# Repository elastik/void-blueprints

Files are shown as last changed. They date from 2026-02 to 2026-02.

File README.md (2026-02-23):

# Void Blueprints

Open-source mushroom cultivation dome — CAD designs, firmware, and build documentation.

The Void is a UV-lit mushroom cultivation chamber that doubles as a living art piece. Print it on any consumer 3D printer, assemble it with readily available components, and grow gourmet mushrooms at home.

## What's Inside

| Directory | Contents | License |
|---|---|---|
| `cad/` | OpenSCAD source files and exported STLs | [CERN-OHL-P-2.0](LICENSE-HARDWARE) |
| `firmware/` | ESP32 PlatformIO project (Void Core) | [MIT](LICENSE-FIRMWARE) |
| `*.md` | Build guides, BOM, assembly instructions | [CC BY 4.0](LICENSE-DOCS) |

## Quick Start

1. **Download STLs** from the [latest release](https://github.com/elastik/void-blueprints/releases/latest)
2. **Print** using settings in [PRINT-SETTINGS.md](PRINT-SETTINGS.md)
3. **Source parts** from [BOM.md](BOM.md) (~$35-85 depending on variant)
4. **Assemble** following [ASSEMBLY-GUIDE.md](ASSEMBLY-GUIDE.md)
5. **Flash firmware** per [FIRMWARE-DOCS.md](FIRMWARE-DOCS.md) (Void Core variant only)

## Variants

| Variant | Description | Electronics | Price Range |
|---|---|---|---|
| **The Void** | Base dome, passive humidity | None | ~$35 |
| **Void Core** | Smart dome with sensors, fans, UV-C | ESP32 + sensors | ~$85 |
| **Dark Dome** | Simplified Void Core, no UV-C | ESP32 + sensors | ~$65 |

## Documentation

- [BUILD-GUIDE.md](BUILD-GUIDE.md) — Complete build walkthrough
- [PARTS-GUIDE.md](PARTS-GUIDE.md) — Component sourcing with suppliers
- [BOM.md](BOM.md) — Bill of materials with prices
- [ASSEMBLY-GUIDE.md](ASSEMBLY-GUIDE.md) — Step-by-step assembly
- [PRINT-SETTINGS.md](PRINT-SETTINGS.md) — 3D printing parameters
- [FIRMWARE-DOCS.md](FIRMWARE-DOCS.md) — Electronics and firmware
- [PRODUCT-SPEC.md](PRODUCT-SPEC.md) — Full engineering specification
- [SPECIES-REQUIREMENTS.md](SPECIES-REQUIREMENTS.md) — Mushroom growing conditions
- [CONTRIBUTING.md](CONTRIBUTING.md) — How to contribute

## Contributing

See [CONTRIBUTING.md](CONTRIBUTING.md) for guidelines. All skill levels welcome — from fixing typos to designing PCBs.

## Community

- Website: [thevoidgrows.com](https://thevoidgrows.com)
- Companion App: [github.com/elastik/thevoidgrows-app](https://github.com/elastik/thevoidgrows-app)
- Social: #VoidGrows #VoidBlueprints

## License

- **Hardware** (CAD, STLs): [CERN-OHL-P-2.0](LICENSE-HARDWARE)
- **Firmware**: [MIT](LICENSE-FIRMWARE)
- **Documentation**: [CC BY 4.0](LICENSE-DOCS)

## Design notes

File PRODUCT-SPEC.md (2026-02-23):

# The Void -- Product Design Specification

> Technical specification for The Void cultivation dome and its variants.
> All design targets derived from SPECIES-REQUIREMENTS.md universal design envelope.
> This document is the engineering reference for prototyping, 3D printing, and injection molding.

---

## 1. Design Overview

### Product Identity

**The Void** is a UV-lit mushroom cultivation dome -- a sealed growing chamber that doubles as a living art piece. It houses a pre-inoculated substrate block (Void Pack) inside a smoked dome on a matte black base, illuminated by UV-A and blue LEDs. USB-C powered. No moving parts in the base model.

### Design Philosophy

1. **Functional cultivation chamber first.** Every aesthetic choice must serve or not compromise growing conditions.
2. **Living art piece.** The dome sits on a desk, shelf, or nightstand. It must look intentional, not like lab equipment.
3. **UV aesthetic defines the brand.** The purple glow under UV-A light IS the product experience.
4. **Simplicity scales down, intelligence scales up.** The base Void is dead simple (LEDs + vents). Complexity lives in Void Core.

### Variant Matrix

| Variant | Description | MSRP | Key Differences |
|---|---|---|---|
| **The Void** | Base cultivation dome. Smoked dome, matte black base, UV-A + blue LEDs, passive airflow, UV-C sterilization, USB-C power. Physical button for mode cycling. | $79 | No microcontroller (or ATtiny). No sensors. No fan. No humidifier. No camera. |
| **Void Core** | Smart dome upgrade. Adds Pi Zero W 2, BME280 sensor, piezo humidifier, PWM fan, camera module, Wi-Fi, app control. | $299 | Active humidity control. Active airflow. Programmable light modes. Timelapse camera. App integration. |
| **Dark Dome** | No-LED variant for bioluminescent species (Panellus stipticus). Same physical shell, no lighting electronics. | $49 | No LEDs. No UV-A, no blue, no UV-C. Passive airflow only. Opaque or clear dome option. |

### Overall Dimensions

**Validated dimensions: 8.0" (203mm) diameter x 10.0" (254mm) total height.**

Validation against species requirements:

| Constraint | Requirement | 8" x 10" Fit | Notes |
|---|---|---|---|
| Substrate block width | Custom 1-2 lb block, ~4.5-5" diameter | 1.5-1.75" clearance on each side | Adequate for lateral fruiting (oysters) |
| Lion's Mane fruiting body | Up to 4-8" diameter | Single fruit body fits; very large specimens may contact dome wall | Acceptable -- large fruit bodies are the success case |
| Oyster cluster spread | 4-6" lateral spread | Fits with clearance; multiple clusters may crowd | Position block so clusters grow upward |
| Reishi antler height | Antlers grow upward, typically 4-8" tall | ~5-6" vertical clearance above substrate surface | Adequate for typical antler growth |
| Shiitake cap diameter | 2-4" individual caps | Fits easily | No concerns |
| Panellus stipticus | Small fruiting bodies, caps up to 3cm | Fits easily | No concerns |
| Airflow volume | ~400 cubic inches chamber volume for passive FAE calculations | Sufficient for convective flow if vents are properly sized | See Section 4 |

**Dimension breakdown:**

| Component | Dimension | Notes |
|---|---|---|
| Total height | 10.0" (254mm) | Dome + base assembled |
| Total diameter | 8.0" (203mm) | Widest point at dome-base junction |
| Dome height | 6.5" (165mm) | From base top to dome apex |
| Base height | 3.5" (89mm) | Houses electronics, substrate platform, and airflow plenum |
| Dome inner diameter | 7.5" (190mm) | Wall thickness reduces usable interior |
| Substrate platform diameter | 5.5" (140mm) | Centered in base; sized for 1-2 lb Void Pack |
| Vertical clearance above substrate | ~5.5-6.0" (140-152mm) | From top of substrate block to dome interior apex |

### Chamber Volume

- Dome interior volume (hemisphere approximation): ~110 cubic inches (~1.8 liters)
- Effective growing chamber (above substrate): ~90-100 cubic inches (~1.5-1.6 liters)
- This small volume is both a feature (humidity retention) and a challenge (CO2 accumulation)

---

## 2. Dome Shell

### Geometry

**Truncated hemisphere with vertical sidewall transition.** The dome is not a pure hemisphere -- it features a short vertical sidewall (approximately 1.0" / 25mm) at the base that transitions into a hemispherical curve. This geometry provides:

1. Maximum interior volume at the widest point where mushroom clusters grow laterally
2. Clean visual silhouette -- more "dome" than "ball"
3. A defined seating lip for the dome-to-base interface
4. Better airflow -- vertical walls at the base allow vents to channel air upward along the dome interior

### Material Options

| Material | Method | Pros | Cons | Recommended For |
|---|---|---|---|---|
| **Smoked polycarbonate** | Injection molding | Excellent impact resistance, natural UV blocking, high clarity with smoke tint, premium feel | Higher mold cost | Production Void (Kickstarter fulfillment) |
| **Smoked PETG** | 3D printing (FDM/SLA) | Printable, good humidity resistance, tintable, adequate clarity | Layer lines (FDM), less impact-resistant than PC | Void Blueprints (community prints), prototyping |
| **Smoked acrylic (PMMA)** | Laser cut + thermoform, or injection mold | Excellent optical clarity, good UV blocking, lightweight | Brittle, scratches easily | Budget production option |

**Primary specification: Smoked polycarbonate for production units.**

### Wall Thickness

| Parameter | Value | Rationale |
|---|---|---|
| Dome wall thickness | 2.0mm (0.079") | Structural integrity + light diffusion. Thin enough for UV-A glow transmission, thick enough to resist accidental drops. |
| Smoke tint level | 50-60% visible light transmission (VLT) | Dark enough to create dramatic UV glow contrast, light enough to see mushrooms growing inside under ambient room light. |
| UV-C opacity | 100% blocked below 300nm | Polycarbonate naturally blocks UV-C. This is the primary safety barrier -- the dome IS the UV-C enclosure. |
| UV-A transmission | 30-50% at 395nm | Allows UV-A glow to be visible from outside the dome. Polycarbonate transmits adequately at 395nm. |

### Finish

- **Exterior:** Smooth, high-gloss smoked tint. The dome should look like smoked glass.
- **Interior:** Smooth. No texture that could trap moisture or contaminants.
- **Anti-fog consideration:** Interior condensation is expected at 85-90% RH. A hydrophilic anti-fog coating (or design that promotes sheeting rather than droplets) prevents obscured viewing. Evaluate anti-fog coatings rated for high-humidity environments during prototyping.

### Dome-to-Base Interface

**Friction-fit with alignment notch.**

- The dome seats into a recessed channel (2mm deep) machined/molded into the base top surface
- A single alignment notch ensures consistent dome orientation (important for vent alignment)
- Friction fit is snug enough to maintain seal but loose enough for easy one-hand removal
- No locking mechanism -- the dome lifts straight off for substrate block swaps
- A silicone gasket ring (1.5mm) in the base channel creates a humidity seal while allowing easy removal

**Magnetic reed switch integration:** A small magnet (6mm x 2mm neodymium disc) is embedded in the dome's seating lip. A corresponding reed switch in the base detects dome presence for the UV-C safety interlock (see Section 7). The dome must be fully seated for UV-C to activate.

---

## 3. Base Unit

### Dimensions

| Parameter | Value | Notes |
|---|---|---|
| Outer diameter | 8.0" (203mm) | Matches dome diameter for flush fit |
| Height | 3.5" (89mm) | Houses substrate platform + electronics + airflow plenum |
| Base footprint | 8.0" diameter circle | Flat bottom for desk stability |
| Weight (empty, base only) | ~350-450g target | Heavy enough for stability, light enough for shipping |

### Material

**Matte black ABS (injection molded) or PETG (3D printed).**

- ABS for production: excellent finish, paintable, dimensionally stable
- PETG for Void Blueprints: printable, humidity-resistant, adequate strength
- Finish: matte black, soft-touch texture on exterior surfaces
- Interior surfaces: smooth for easy cleaning

### Internal Layout (Top to Bottom)

```
    +----- Dome seating channel (top rim) -----+
    |                                           |
    |  [Substrate platform - raised 0.5"]       |
    |  [  5.5" diameter, with drain slots  ]    |
    |                                           |
    |--- LED ring (UV-A + Blue) mounted here ---|
    |                                           |
    |  [Airflow plenum - 1.0" height]           |
    |  [  Intake vents around perimeter    ]    |
    |                                           |
    |--- Electronics shelf ----------------------|
    |  [LED driver / UV-C control / button]     |
    |  [USB-C port at rear]                     |
    |                                           |
    +-- Base bottom (flat, with rubber feet) ----+
```

### Substrate Platform

| Parameter | Value | Notes |
|---|---|---|
| Platform diameter | 5.5" (140mm) | Centered; sized for custom 1-2 lb Void Pack blocks |
| Platform depth (recessed) | 0.5" (13mm) | Shallow well to center the block and catch drainage |
| Surface | Perforated / slotted | 4-6 drain slots for excess moisture to drain into airflow plenum below |
| Rim height | 0.25" (6mm) raised lip | Prevents block from sliding during dome removal |

### Cable Routing

- USB-C port location: rear-center of base, recessed 3mm into the housing
- Internal cable routing: flat flex cable from USB-C port to electronics shelf
- Cable exit: downward-facing port so cable routes down to desk surface cleanly
- Strain relief: molded into the port recess

### Stability

- Four silicone rubber feet (12mm diameter, 3mm tall) on base bottom
- Total assembled weight target: 600-800g (dome + base, no substrate)
- Center of gravity is low (electronics and base mass are below midpoint)
- Stable on typical desk surfaces; no risk of tipping from dome removal

---

## 4. Airflow System (Fresh Air Exchange)

### Design Challenge

CO2 management is the #1 engineering challenge for the dome. From SPECIES-REQUIREMENTS.md:

- Lion's Mane (flagship): requires < 800 ppm CO2, 5-8 air exchanges/hour
- Blue/Pink Oyster: requires < 800-1000 ppm CO2, 4-6 exchanges/hour
- Chamber volume is only ~1.5-1.6 liters of effective growing space
- A respiring substrate block in this small volume accumulates CO2 rapidly
- The dome must exchange air passively (no fan in base Void) while maintaining 85-90% RH

### Approach: Passive Convective Airflow

The base Void uses **passive convective (chimney effect) airflow** -- warm, CO2-rich, humid air rises and exits through upper dome vents, while cool fresh air enters through lower base intake vents.

**Why passive works:** The substrate block generates metabolic heat (0.5-2 degrees F above ambient), creating a temperature differential that drives natural convection. The dome's vertical profile (10" tall) provides sufficient chimney height for meaningful convective flow.

### Vent Design

#### Intake Vents (Base)

| Parameter | Value | Notes |
|---|---|---|
| Location | Lower perimeter of base unit, evenly spaced | 360-degree intake for omnidirectional fresh air |
| Quantity | 8 slots | Evenly distributed around circumference |
| Individual slot size | 15mm wide x 5mm tall (0.6" x 0.2") | Small enough for contamination barrier, large enough for airflow |
| Total intake area | ~600 mm2 (~0.93 in2) | Sized for target exchange rate (see calculations below) |
| Filter | Micropore tape (3M Micropore or equivalent) | Blocks contaminant spores (>0.3 um) while allowing air passage |
| Adjustable | No (base Void) / Yes (Void Core -- motorized damper) | Base Void has fixed vents; simplicity over tunability |

#### Exhaust Vents (Dome Upper)

| Parameter | Value | Notes |
|---|---|---|
| Location | Upper third of dome, near apex | Warm CO2-rich air naturally rises here |
| Quantity | 4 vent holes | Evenly spaced around dome circumference, ~60 degrees from apex |
| Individual hole diameter | 12mm (0.47") | Sized for exhaust flow rate |
| Total exhaust area | ~452 mm2 (~0.70 in2) | Slightly less than intake -- creates slight positive pressure tendency |
| Filter | Micropore tape (replaceable) | User-accessible for replacement; contaminant barrier |
| Cover design | Recessed ring with snap-in filter disc | Clean exterior appearance; easy filter swap |

#### Airflow Rate Calculation

Target: 4-6 air exchanges per hour (satisfies all species except antler reishi).

- Chamber volume: ~1.6 liters
- At 4 exchanges/hour: 6.4 liters/hour = 107 ml/min = 1.78 ml/sec
- At 6 exchanges/hour: 9.6 liters/hour = 160 ml/min = 2.67 ml/sec

Natural convection through the vent openings at a 1-2 degree F temperature differential and 10" chimney height produces estimated flow rates of 2-5 ml/sec through the specified vent areas. This falls within the target range.

**Uncertainty note:** These are engineering estimates based on simplified chimney effect calculations. Actual airflow depends on ambient conditions (room air currents, temperature, barometric pressure), vent geometry, and micropore tape resistance. Prototype testing with CO2 monitoring is essential to validate vent sizing and may require iteration.

### Airflow Path

```
CROSS-SECTION VIEW (not to scale):

              Exhaust vents (x4)
                 \   |   /
          +-------[V][V]--------+
         /    Dome (smoked PC)    \
        /                          \
       |   ~~~~~~~~~~~~~~~~~~~~~~~~ |   <- Humid air layer
       |                            |
       |    +------------------+    |
       |    | Mushroom fruiting|    |
       |    |    bodies grow   |    |
       |    |     upward       |    |
       |    +------------------+    |
       |    |  Void Pack block |    |
       |    | (substrate 4.5") |    |
       |    +--------+---------+    |
       |             |drain slots   |
       +====[LED RING (UV-A+Blue)]===+  <- Dome/base junction
       |                            |
       |   [Airflow plenum 1.0"]    |
       |                            |
  -->[V]  Intake      Intake   [V]<--   <- Base intake vents (x8)
       |   vents       vents        |      Fresh air enters
       |                            |
       |  [Electronics: LED driver] |
       |  [UV-C ctrl] [Button]      |
       |        [USB-C port]        |
       +----(rubber feet)x4---------+
       ================================   <- Desk surface
```

**Flow path:** Fresh air enters through base intake vents -> passes through airflow plenum beneath substrate platform -> rises through drain slots in platform -> passes over/around substrate block and fruiting bodies -> warm CO2-rich air rises to dome apex -> exits through upper dome exhaust vents.

### Void Core Upgrade: Active Airflow

| Parameter | Value | Notes |
|---|---|---|
| Fan type | 30mm axial fan (5V DC) | Mounted in base airflow plenum |
| Fan speed | PWM controlled, 0-5000 RPM | App-adjustable; auto-mode based on CO2 sensor reading |
| Noise level | < 25 dB at typical operating speed | Near-silent operation |
| Air exchange rate | 4-12 exchanges/hour (adjustable) | Higher rates available for CO2-sensitive species |
| CO2 sensor | SCD30 or SCD40 (Sensirion) via BME280 combo | Triggers fan speed increase when CO2 > 600 ppm |

### Reishi Antler Mode

For reishi antler form cultivation (requires > 2000 ppm CO2), users should cover or tape over 6 of 8 base intake vents and 3 of 4 dome exhaust vents. This reduces air exchange to ~1 exchange/hour, allowing CO2 to accumulate.

- **Base Void:** Manual vent covering with included silicone plugs (4 plugs included with Reishi Void Pack)
- **Void Core:** App-controlled motorized dampers on intake and exhaust vents

---

## 5. Humidity Management

### Design Target

**85-90% RH** inside the dome during active fruiting. This satisfies all target species:

| Species | Required RH | 85-90% Target | Status |
|---|---|---|---|
| Lion's Mane | 85-95% | Within range | OK |
| Blue Oyster | 85-95% | Within range | OK |
| Pink Oyster | 85-95% (min 70%) | Within range | OK |
| Shiitake | 85-95% early, 60-80% late | Within range for early; naturally drops as vents exchange air in late stage | OK |
| Reishi | 80-90% | Within range | OK |
| Panellus stipticus | 85-95% | Within range | OK |

### Base Void: Passive Humidity (No Moving Parts)

The base Void maintains humidity through three mechanisms:

1. **Substrate moisture:** The Void Pack substrate block is hydrated to 60-65% moisture content. As the mycelium respires, it releases moisture vapor into the chamber. A 1-2 lb block contains approximately 300-600 ml of water, providing sustained humidity for the full grow cycle (2-4 weeks for most species).

2. **Sealed dome retention:** The smoked polycarbonate dome with silicone gasket creates a near-sealed environment. Humidity loss occurs only through the sized vents, which are restricted by micropore tape. This natural retention keeps RH high.

3. **Vent sizing balance:** The vents are sized to allow adequate FAE (4-6 exchanges/hour) while losing minimal humidity. Micropore tape on vents acts as a partial humidity barrier -- air passes through but water vapor transport is reduced. The vent areas specified in Section 4 were designed to balance CO2 removal against humidity retention.

**Expected behavior:** In a typical indoor environment (68-75 degrees F, 40-60% ambient RH), the dome interior should stabilize at 80-92% RH with a fresh Void Pack. As the substrate dries over the grow cycle, RH gradually decreases. For multi-flush grows, users soak the substrate block between flushes to rehydrate.

**Condensation management:** At 85-90% RH, condensation will form on the dome interior, especially in the upper dome where warm moist air meets the cooler dome surface. This is normal and expected. The dome geometry (curved interior) encourages condensation droplets to run down the walls and return to the base rather than dripping directly onto fruiting bodies. The anti-fog coating (Section 2) promotes sheeting over beading for better visibility.

### Void Core: Active Humidity Control

| Parameter | Value | Notes |
|---|---|---|
| Humidifier type | Piezoelectric ultrasonic mist disc (20mm, 113 KHz) | Low-power, fine mist, no heat |
| Reservoir | 100 ml integrated reservoir in base | Refill via pour port on base exterior; lasts ~3-5 days at normal operation |
| Mist output | 20-40 ml/hour (adjustable via PWM) | Triggered by BME280 humidity reading |
| Control logic | Maintain setpoint +/- 2% RH | Default 88% RH; user-adjustable via app (80-95% range) |
| Fill indicator | LED color change or app notification when reservoir low | Prevents dry-run damage to piezo disc |

### Humidity Monitoring (Void Core Only)

The BME280 sensor (temperature + humidity + barometric pressure) provides real-time RH data to the Pi Zero W 2. The control loop:

1. Read humidity every 30 seconds
2. If RH < (setpoint - 2%), activate mist disc at duty cycle proportional to deficit
3. If RH > (setpoint + 2%), pause mist disc; optionally increase fan speed briefly to vent excess
4. Log data for timelapse correlation and grow analytics in the Void app

---

## 6. Access & Maintenance

### Dome Removal: Lift-Off Design

The dome **lifts straight up and off** the base. No hinge, no twist-lock, no bayonet mount.

**Rationale:**
- Simplest possible mechanism (no moving parts, no wear points)
- One-hand operation: grip dome at widest point, lift straight up
- Full 360-degree access to the interior -- no hinge blocking one side
- Easy to clean -- dome is completely separable
- Easiest manufacturing (no hinge hardware, no alignment mechanisms)
- Compatible with UV-C safety interlock (magnetic reed switch detects dome presence)

### Substrate Block Replacement Workflow

**Standard grow cycle (base Void):**

1. Receive Void Pack (pre-colonized substrate block in sealed bag)
2. Remove Void Pack from bag
3. Lift dome off base
4. Place Void Pack on substrate platform (centered in recessed well)
5. Place dome back on base (align notch)
6. Press button to select light mode (UV-A glow, blue fruiting light, or both)
7. Wait 7-21 days (species dependent) -- mushrooms fruit
8. Lift dome to harvest mushrooms
9. Replace dome; continue for additional flushes (soak block between flushes)
10. When spent, remove old block
11. (Optional) Press and hold button for UV-C sterilization cycle (15 minutes, dome must be seated)
12. Place new Void Pack; repeat from step 5

**Between-grow cleaning:**

1. Remove spent substrate block; discard or compost
2. Lift dome off base
3. Wipe dome interior with damp cloth (mild soap if needed)
4. Wipe substrate platform and base interior
5. Replace micropore tape on vents if contaminated or clogged (every 2-3 grow cycles)
6. (Optional) Run UV-C sterilization cycle with dome seated and chamber empty
7. Place new Void Pack

### Micropore Tape Replacement

- Intake vent filters: accessed from base exterior; peel old tape, apply new strip
- Exhaust vent filters: accessed from dome exterior; snap-out filter disc, replace tape, snap back in
- Replacement tape included in Void Pack packaging (enough for one grow cycle)
- Also available separately or in bulk from standard suppliers (3M Micropore surgical tape)

### Maintenance Schedule

| Task | Frequency | Difficulty |
|---|---|---|
| Harvest mushrooms | Every 7-21 days during fruiting | Easy -- lift dome, cut/twist fruit bodies |
| Soak substrate block (between flushes) | Every 10-14 days | Easy -- remove block, soak in water 12-24 hours, return |
| Replace Void Pack | Every 1-3 months (species dependent) | Easy -- swap blocks |
| Wipe dome interior | Between grows | Easy -- damp cloth |
| Replace micropore tape on vents | Every 2-3 grows | Easy -- peel and stick |
| UV-C sterilization cycle | Between grows (recommended) | Easy -- press and hold button, wait 15 min |
| Refill humidifier reservoir (Void Core) | Every 3-5 days | Easy -- pour water into fill port |

### Dark Dome Variant Notes

The Dark Dome follows the same physical design as The Void with these differences:

- **No LED ring:** The base has no UV-A, blue, or UV-C LEDs. The LED ring position is left empty (cost savings).
- **No electronics:** No LED driver, no button, no USB-C port. The Dark Dome is a purely passive growing chamber.
- **No UV-C sterilization:** Users clean the Dark Dome manually between grows (wipe down with dilute hydrogen peroxide or isopropyl alcohol).
- **Dome tint option:** May be offered in clear (untinted) polycarbonate for maximum bioluminescence visibility, or standard smoked tint. Evaluate during prototyping which shows bioluminescent glow better.
- **All passive systems identical:** Dome shell, base unit, substrate platform, airflow vents, humidity management -- all same as base Void.
- **Lower price ($49)** reflects removal of all electronic components.

---

## Cross-Section Diagram -- Full Assembly

```
                          ___
                        /     \           <- Dome apex
                      /  (ExV)  \         <- Exhaust vent (x4 around this zone)
                    /             \
                   /               \
                  |   ~~~HUMID~~~   |     <- High-humidity growing zone (85-90% RH)
                  |                 |
                  |  +===========+  |
                  |  ||  FRUIT  ||  |     <- Mushroom fruiting bodies
                  |  || BODIES  ||  |        (Lion's Mane tendrils, oyster shelves, etc.)
                  |  +===========+  |
                  |  |  VOID     |  |     <- Void Pack substrate block
                  |  |  PACK     |  |        (~4.5" W x 3" H, 1-2 lbs)
                  |  |  BLOCK    |  |
                  |  +-----+-----+  |
                  |  | platform  |  |     <- Substrate platform (5.5" dia, perforated)
    Dome -------> |  +--+--+--+--+  |
    seated in --> ====[LED RING]====== <-- UV-A (395nm) + Blue (450nm) LEDs
    base channel  |     (Magnet^)   |     <- Magnet in dome lip / Reed switch in base
                  |                 |
               -->[InV]  PLENUM [InV]<--  <- Intake vents (x8) with micropore tape
                  |    (airflow)    |        Fresh air enters here
                  |  +-----------+  |
                  |  | ELECTR.   |  |     <- LED driver, UV-C LED (points up),
                  |  | [UV-C ^]  |  |        mode button, USB-C connector
                  |  | [BTN][USB]|  |
                  +--+-----------+--+
                    (  rubber feet  )     <- 4x silicone feet
               ========================     Desk surface

Legend:
  ExV  = Exhaust vent (dome, upper)       InV = Intake vent (base, lower)
  ^    = UV-C LED (points upward through platform drain slots into chamber)
  LED RING = UV-A + Blue LEDs at dome/base junction, pointing up into dome
  ~~~ = Humid air / mist zone
```

**Key dimensions in cross-section:**
- Overall: 8.0" wide x 10.0" tall
- Dome: 6.5" tall (including 1.0" vertical sidewall)
- Base: 3.5" tall
- Substrate clearance above block: ~5.5-6.0" to dome apex
- LED ring position: at dome/base junction, angled upward at ~30 degrees into dome interior
- UV-C LED position: in electronics bay, pointing upward through platform drain slots

---

## 7. Lighting System

The dome uses three distinct lighting subsystems serving different purposes. The base Void includes all three; the Dark Dome includes none.

### 7.1 UV-A Aesthetic Lighting (395nm)

The brand-defining purple glow. Runs continuously during the 12-hour light cycle.

| Parameter | Specification | Notes |
|---|---|---|
| **Wavelength** | 395nm | Strong visible purple/violet; cost-effective; good UV-A transmission through smoked PC dome |
| **LED type** | 5050 SMD UV-A LEDs | Standard package, widely available, easy to solder |
| **Quantity** | 6 LEDs in ring configuration | Evenly spaced around LED ring at dome/base junction |
| **Power per LED** | 60-80 mW each at 20mA | Low-power; ample for 8" dome illumination |
| **Total UV-A power** | ~0.4-0.5W | Minimal power draw |
| **Beam angle** | 120 degrees | Wide coverage; LEDs angled 30 degrees upward into dome |
| **Voltage** | 3.0-3.4V forward (driven from 5V with resistor) | Standard UV-A LED specs |
| **Placement** | LED ring at dome/base junction, pointing upward | Uplighting creates dramatic shadows on mushroom forms |
| **Operation** | 12h on / 12h off (timer circuit) | Matches fruiting light cycle |

**Dark Dome:** No UV-A LEDs. Position left empty on PCB (or Dark Dome uses simplified PCB without LED pads).

### 7.2 Blue Fruiting Light (450nm)

Provides the primary photomorphogenic stimulus that triggers pinning and fruiting in all target species.

| Parameter | Specification | Notes |
|---|---|---|
| **Wavelength** | 450nm (royal blue) | Peak of mushroom blue-light photoreceptor response (430-470nm) |
| **LED type** | 5050 SMD blue LEDs | Same package as UV-A for unified ring design |
| **Quantity** | 6 LEDs interleaved with UV-A in ring | Alternating UV-A / Blue around the ring (12 LEDs total in ring) |
| **Power per LED** | 60-80 mW each at 20mA | Sufficient for 500+ lux at substrate surface in small dome |
| **Total blue power** | ~0.4-0.5W | Low power; high efficacy in small chamber |
| **Estimated lux at substrate** | 500-800 lux | Satisfies all species minimum (200-2000 lux range); see SPECIES-REQUIREMENTS.md |
| **Operation** | 12h on / 12h off (same timer as UV-A) | Combined on single timer circuit |

**Species light coverage at 500-800 lux:**

| Species | Required Lux | 500-800 Provided | Status |
|---|---|---|---|
| Lion's Mane | 200-500 | Above minimum | OK (at upper end of range) |
| Blue Oyster | 500-1000 | Within range | OK |
| Pink Oyster | 500-1000 | Within range | OK |
| Shiitake | 500-2000 | At low end | Adequate for basic fruiting |
| Reishi | 750-1500 | At low end | Adequate for basic fruiting |

**Note:** Shiitake and Reishi have higher light requirements. The base Void provides adequate (not optimal) light for these species. The Void Core could boost light intensity through PWM control and supplemental LEDs.

### 7.3 UV-C Sterilization (275nm)

Germicidal sterilization between grows. ONLY activates when dome is sealed and user deliberately triggers the cycle.

| Parameter | Specification | Notes |
|---|---|---|
| **Wavelength** | 275nm | Best commercial UV-C LED availability; excellent germicidal effectiveness |
| **LED type** | 3535 SMD UV-C LED (Seoul Viosys or equivalent) | Standard UV-C LED package |
| **Quantity** | 1 LED | Single LED sufficient for small dome volume |
| **Electrical input** | 1.0-1.5W | Typical UV-C LED power consumption |
| **UV-C output** | 30-40mW radiant power | 2-4% wall-plug efficiency (typical for UV-C LEDs) |
| **Beam angle** | 120 degrees | Wide angle for maximum surface coverage |
| **Placement** | Electronics bay, pointing upward through substrate platform drain slots | Illuminates dome interior from below |
| **Target dose** | 100 mJ/cm2 | Achieves 99% kill of Trichoderma (primary mushroom contaminant) |
| **Cycle time** | 15 minutes (auto-shutoff) | 0.1 mW/cm2 x 900s = 90 mJ/cm2; meets target with margin for geometry |
| **Extended cycle** | 30 minutes (optional, Void Core app selection) | ~180 mJ/cm2 for more resistant contaminants (Aspergillus spp.) |
| **Lifetime** | ~9,000 hours | Far exceeds usage (15 min per grow cycle = decades of service) |

### 7.4 UV-C Safety Interlock System

UV-C radiation at the dome's target dose (90-180 mJ/cm2) is 15-30x the ACGIH 8-hour exposure limit for humans. The safety interlock is not optional -- it is a critical safety system.

| Safety Feature | Implementation | Failure Mode |
|---|---|---|
| **Magnetic dome-presence sensor** | 6mm neodymium disc magnet in dome lip + reed switch in base | UV-C cannot activate if dome is removed or not fully seated. Reed switch is normally-open; only closes when magnet is within 5mm. |
| **Hardware interlock (not software)** | Reed switch is wired in series with UV-C LED power line | Even if microcontroller fails or is absent (base Void), UV-C physically cannot receive power without dome present. Pure hardware safety. |
| **Deliberate activation only** | Press-and-hold button for 3 seconds to start UV-C cycle | Prevents accidental activation. Button tap cycles light modes; only sustained press starts sterilization. |
| **Hardware timer auto-shutoff** | NE555 or similar timer IC limits UV-C to 15 minutes maximum | Even without microcontroller, UV-C automatically stops. No software dependency. |
| **Red LED indicator** | Dedicated red LED on base exterior, visible from all sides | Lit during entire UV-C cycle. Users know not to remove dome. |
| **UV-C opaque dome** | Polycarbonate dome blocks 100% of UV-C below 300nm | Dome material IS the primary radiation enclosure. Standard PC blocks UV-C inherently. |
| **Warning label** | Permanent label on base: "CAUTION: UV-C germicidal light. Do not operate without dome in place." | Required for consumer product safety compliance. |
| **Void Core: app confirmation** | Smart version requires tap-to-confirm in app before UV-C starts | Additional software layer on top of hardware interlock. Not a replacement. |

**Key design principle:** All UV-C safety mechanisms are hardware-based. The base Void has no microcontroller, so safety cannot depend on software. The magnetic interlock + hardware timer ensure UV-C is safe even if every other component fails.

### 7.5 Light Modes

**Base Void (physical button cycles through modes):**

| Mode | UV-A (395nm) | Blue (450nm) | UV-C (275nm) | Trigger |
|---|---|---|---|---|
| 1. Void Glow | ON | ON | OFF | Button tap (default) |
| 2. UV Only | ON | OFF | OFF | Button tap |
| 3. Blue Only | OFF | ON | OFF | Button tap |
| 4. Off | OFF | OFF | OFF | Button tap |
| 5. Sterilize | OFF | OFF | ON (15 min) | Button hold 3 sec (dome must be seated) |

Mode cycling: tap button to advance 1 -> 2 -> 3 -> 4 -> 1. The 12h timer applies to modes 1-3 (auto-off after 12h, auto-on after 12h dark). Mode 5 (sterilize) is independent of the cycle timer.

**Void Core (app-controlled, all of the above plus):**

| Mode | Description | LEDs Used |
|---|---|---|
| Deep Space | Slow UV-A pulse with deep blue undertone | UV-A + Blue (PWM dimming) |
| Bioluminescence | Minimal light, enhances natural glow for Panellus | Blue at 5% duty cycle |
| Aurora | Slow color sweep across UV-A intensity levels | UV-A (PWM sweep) |
| Blacklight | Maximum UV-A intensity | UV-A at 100% |
| Music Sync | Beat-reactive UV-A + Blue flashing | UV-A + Blue (microphone input) |
| Custom | User-defined intensity and timing per channel | All channels, app-configured |

### 7.6 RGB LED System (Void Core Only)

| Parameter | Specification | Notes |
|---|---|---|
| **LED type** | WS2812B (addressable RGB, 5050 package) | Individual color control per LED; single data line |
| **Quantity** | 8 LEDs in secondary ring | Separate from UV-A/Blue ring; mounted slightly lower in base |
| **Power per LED** | 60mA max (full white) | Typical draw at accent brightness: 20-30mA each |
| **Total RGB power** | 0.5-1.5W (depending on mode) | Full white all-on = 2.4W max; typical accent modes much lower |
| **Data protocol** | Single-wire NZR (WS2812B native) | One GPIO pin from Pi Zero W 2 |
| **Purpose** | Color accent modes (Aurora, Music Sync, etc.), status indication | Adds color variety beyond UV-A purple |

**Not included in base Void.** RGB is a Void Core feature only. Base Void's $79 MSRP requires minimal component cost.

---

## 8. Control Electronics

### 8.1 Base Void: Minimal Electronics

The base Void uses no microcontroller (or optionally an ATtiny85 for mode memory). The design philosophy: **fewer components = lower cost, higher reliability, lower failure rate.**

| Component | Purpose | Notes |
|---|---|---|
| **USB-C PD sink IC** | Negotiate 5V from any USB-C source | CH224K or IP2721; tiny SOT-23 package; ensures 5V delivery from USB-C |
| **LED driver (constant current)** | Drive UV-A + Blue LED ring | PT4115 or similar; single IC drives 12 LEDs in 2 strings of 6 |
| **555 timer IC (x2)** | (1) 12h on/off light cycle, (2) 15-min UV-C auto-shutoff | NE555 or LMC555 (CMOS for lower power). Hardware timing, no software dependency. |
| **Momentary push button** | Mode cycling + UV-C activation (3-sec hold) | Waterproof silicone-cap tactile switch; mounted on base exterior |
| **Reed switch** | UV-C safety interlock (dome presence detection) | Normally-open; closes when dome magnet is within 5mm |
| **Red indicator LED** | UV-C cycle active indicator | Standard 3mm red LED + resistor |
| **UV-C LED** | Sterilization | Seoul Viosys 275nm, 3535 package |
| **Decoupling capacitors** | Power filtering | Standard 100uF + 0.1uF ceramic |
| **Resistors** | LED current limiting, timer configuration | Standard 1/4W through-hole or 0805 SMD |

**Optional: ATtiny85 microcontroller** ($0.50-1.00 in volume). Adds mode memory (remembers last selected mode after power cycle) and enables button hold detection for UV-C. If the 555 timer + discrete logic approach is too cumbersome for button-hold detection, the ATtiny85 replaces both 555 timers and the discrete logic with a single 8-pin IC. Total firmware: ~500 bytes.

**Total component count (base Void): 15-25 components.** This is a deliberately simple circuit. The entire electronics assembly can fit on a single 2-layer PCB, 50mm x 30mm.

### 8.2 Void Core: Smart Electronics

The Void Core adds intelligence, sensors, and connectivity on top of the base Void electronics.

| Component | Purpose | Specification |
|---|---|---|
| **Raspberry Pi Zero W 2** | Main controller | Quad-core ARM, Wi-Fi, Bluetooth, 512MB RAM, USB OTG, CSI camera port |
| **BME280 sensor** | Temperature + humidity + barometric pressure | I2C interface; +/- 1 degree C, +/- 3% RH accuracy |
| **SCD40 CO2 sensor** | CO2 concentration monitoring | I2C; range 400-5000 ppm; +/- 50 ppm accuracy. Optional add-on for advanced growers. |
| **Piezoelectric humidifier disc** | Active mist generation | 20mm, 113 KHz; 5V DC; ~1.5W when active |
| **30mm axial fan** | Active airflow (FAE) | 5V DC, PWM speed control, <25 dB at typical speed |
| **Camera module** | Timelapse photography | Pi Zero camera module (5MP or 8MP); ribbon cable to CSI port |
| **WS2812B RGB ring** | Color accent lighting | 8 addressable LEDs; single data pin |
| **microSD card** | OS + timelapse storage | 16GB minimum; Raspberry Pi OS Lite |
| **USB-C hub/splitter** | Power distribution to Pi + base electronics | Internal USB-C to micro-USB adapter for Pi power |
| **Motorized damper (x2)** | Adjustable intake/exhaust vent aperture | Small servo or solenoid; app-controlled vent sizing |

**Communication:** Wi-Fi (2.4 GHz) to the Void app (web-based dashboard). BLE for initial setup/pairing.

**Software (out of scope for this spec):** The Void Core runs a Python-based control daemon on Raspberry Pi OS Lite. Firmware design is a separate specification document.

### 8.3 Wiring Architecture Description

**Base Void:**
```
USB-C port
    |
    v
[USB-C PD Sink IC] --> 5V rail
    |
    +---> [LED Driver] ---> UV-A LED string (6x series)
    |         |
    |         +-----------> Blue LED string (6x series)
    |
    +---> [555 Timer #1] ---> 12h cycle control (enables/disables LED driver)
    |
    +---> [Button] ---> [Mode logic] ---> LED driver enable/channel select
    |                        |
    |                        +---> [3-sec hold detect] ---> UV-C trigger
    |
    +---> [Reed switch] ---> [555 Timer #2] ---> UV-C LED
    |                                             (interlock in series)
    |
    +---> [Red indicator LED] (parallels UV-C power)
```

**Void Core (adds to above):**
```
5V rail
    |
    +---> [Pi Zero W 2] ---> I2C bus ---> [BME280] + [SCD40]
    |         |
    |         +---> CSI ---> [Camera module]
    |         |
    |         +---> GPIO ---> [WS2812B data]
    |         |
    |         +---> PWM ---> [Fan speed control]
    |         |
    |         +---> GPIO ---> [Humidifier on/off]
    |         |
    |         +---> GPIO ---> [Motorized dampers]
    |         |
    |         +---> WiFi ---> [Void app]
    |
    +---> [Piezo humidifier driver] ---> [Humidifier disc]
    |
    +---> [Fan] (5V, PWM from Pi)
```

---

## 9. Power Architecture

### 9.1 USB-C Power Input

| Parameter | Specification | Notes |
|---|---|---|
| **Connector** | USB Type-C receptacle | Rear-center of base |
| **Negotiated voltage** | 5V (USB 2.0 default) | Base Void needs only 5V/500mA minimum |
| **PD negotiation** | CH224K sink IC (base Void: 5V only) | Simple, no PD negotiation needed for base -- just 5V default |
| **Void Core PD** | 5V/3A (15W) via USB-C PD | Pi Zero + sensors + fan + humidifier need more current |
| **Cable** | USB-C to USB-A or USB-C to USB-C (user-supplied) | Standard cables; any USB charger 5V/1A+ works for base Void |

### 9.2 Power Budget -- Base Void

| Component | Voltage | Current (typ) | Current (max) | Power (typ) | Power (max) |
|---|---|---|---|---|---|
| UV-A LEDs (6x 395nm) | 3.2V via 5V | 120mA | 150mA | 0.40W | 0.50W |
| Blue LEDs (6x 450nm) | 3.0V via 5V | 120mA | 150mA | 0.36W | 0.45W |
| LED driver IC | 5V | 10mA | 15mA | 0.05W | 0.08W |
| 555 timer ICs (x2) | 5V | 2mA | 4mA | 0.01W | 0.02W |
| UV-C LED (when active) | 6.5V via 5V boost | 250mA | 350mA | 1.25W | 1.75W |
| Red indicator LED | 5V | 10mA | 15mA | 0.05W | 0.08W |
| USB-C PD sink IC | 5V | 1mA | 2mA | 0.01W | 0.01W |
| Button + reed switch | -- | negligible | negligible | -- | -- |
| **TOTAL (normal grow)** | | **~253mA** | **~321mA** | **~0.83W** | **~1.05W** |
| **TOTAL (UV-C active)** | | **~263mA** | **~371mA** | **~1.32W** | **~1.85W** |

**Base Void power draw: 0.8-1.1W during normal growing (lights on). Well under the 5W target.** Even with UV-C active, total is under 2W. This is comfortably within USB 2.0's 500mA/2.5W limit.

**Note:** UV-A and UV-C are never on simultaneously. UV-C only runs between grows when the dome is sealed and lights are off. So the real peak is UV-C + red indicator = ~1.3W, not UV-A + Blue + UV-C combined.

### 9.3 Power Budget -- Void Core

| Component | Voltage | Current (typ) | Current (max) | Power (typ) | Power (max) |
|---|---|---|---|---|---|
| All base Void components | 5V | 253mA | 321mA | 0.83W | 1.05W |
| Raspberry Pi Zero W 2 | 5V | 300mA | 500mA | 1.50W | 2.50W |
| BME280 sensor | 3.3V (from Pi) | 1mA | 2mA | 0.003W | 0.01W |
| SCD40 CO2 sensor (optional) | 3.3V (from Pi) | 15mA | 20mA | 0.05W | 0.07W |
| Piezo humidifier | 5V | 300mA | 400mA | 1.50W | 2.00W |
| 30mm fan | 5V | 80mA | 150mA | 0.40W | 0.75W |
| WS2812B RGB ring (8x) | 5V | 160mA | 480mA | 0.80W | 2.40W |
| Camera module | 3.3V (from Pi) | 50mA | 100mA | 0.17W | 0.33W |
| Motorized dampers (x2) | 5V | 50mA | 150mA | 0.25W | 0.75W |
| **TOTAL (normal grow)** | | **~1,209mA** | | **~5.5W** | |
| **TOTAL (all active)** | | | **~2,123mA** | | **~9.9W** |

**Void Core typical power: ~5.5W. Peak (all systems active): ~10W.** Requires USB-C PD at 5V/3A (15W) for headroom. Standard USB 2.0 is insufficient for Void Core.

### 9.4 Power Protection

| Protection | Implementation | Notes |
|---|---|---|
| **Overcurrent** | Resettable PTC fuse (500mA for base Void; 2A for Void Core) | Protects against short circuits. Self-resetting after fault clears. |
| **Reverse polarity** | Not applicable (USB-C connector is keyed) | USB-C physical connector prevents reverse insertion |
| **ESD protection** | TVS diode on USB-C VBUS line | Standard ESD protection for consumer electronics |
| **Overvoltage** | Zener clamp at 5.5V on VBUS rail | Protects against non-compliant chargers delivering >5V |

### 9.5 Power States

| State | Components Active | Power Draw | Duration |
|---|---|---|---|
| **Off** | None (USB disconnected or mode 4) | 0W | -- |
| **Standby** | 555 timer only (during 12h dark period) | <0.01W | 12 hours |
| **Growing (lights on)** | UV-A + Blue LEDs + timer | ~0.8-1.1W | 12 hours |
| **Sterilizing** | UV-C LED + red indicator + timer | ~1.3W | 15 minutes |
| **Void Core idle** | Pi Zero + sensors (lights in dark period) | ~1.6W | 12 hours |
| **Void Core growing** | Pi + sensors + LEDs + fan + occasional mist | ~5.5W | 12 hours |
| **Void Core peak** | All systems active simultaneously | ~10W | Brief bursts |

---

## 10. Connector & Interface

### 10.1 Physical Connectors

| Connector | Location | Purpose | Variant |
|---|---|---|---|
| **USB-C receptacle** | Rear-center of base, recessed 3mm | Power input (+ data for Void Core) | Void, Void Core |
| **None (Dark Dome)** | -- | Dark Dome has no electrical connections | Dark Dome |

The USB-C port serves dual purpose on Void Core:
- **Power:** 5V/3A via USB-C PD
- **Data:** USB 2.0 data lines connect to Pi Zero W 2 for firmware updates, SSH access, and direct file transfer (timelapse images)

### 10.2 Physical Controls -- Base Void

| Control | Type | Location | Function |
|---|---|---|---|
| **Mode button** | Waterproof silicone-cap tactile switch, 12mm diameter | Base exterior, front-center, easily reachable | Tap: cycle light modes (1->2->3->4->1). Hold 3 sec: start UV-C sterilization cycle. |

Single button design rationale:
- One button is all the base Void needs. Fewer controls = less confusion = lower cost.
- Mode memory (if ATtiny85 is used): dome remembers last mode after power cycle.
- No touch sensor -- tactile button provides positive feedback and is more reliable in high-humidity environments.

### 10.3 Visual Indicators -- Base Void

| Indicator | Type | Location | Meaning |
|---|---|---|---|
| **Red LED** | 3mm through-hole LED | Base exterior, front, next to mode button | ON = UV-C sterilization cycle active. Do NOT remove dome. OFF = safe. |

No other indicators on base Void. Light mode is indicated by the dome glow itself (purple = UV-A, blue = Blue, purple+blue = Void Glow, dark = off).

### 10.4 Void Core Interfaces

| Interface | Type | Purpose |
|---|---|---|
| **Wi-Fi (2.4 GHz)** | Pi Zero W 2 built-in | App communication, cloud sync, firmware OTA updates |
| **Bluetooth Low Energy** | Pi Zero W 2 built-in | Initial setup/pairing, proximity-based features |
| **USB 2.0 data** | Via USB-C connector | SSH, file transfer, firmware flash (development/advanced users) |
| **CSI camera port** | Ribbon cable (internal) | Pi Camera Module connection |
| **I2C bus** | Internal (3.3V) | BME280, SCD40 sensors |

**No additional physical buttons or ports on Void Core.** All control is via the Void app or USB. The base Void's mode button still functions as a fallback (cycle modes locally if Wi-Fi is unavailable).

### 10.5 Dark Dome Interface

The Dark Dome has **no electronic interfaces whatsoever.** No USB port. No button. No LEDs. No indicators. It is a purely passive cultivation chamber -- a dome on a base with vents.

This extreme simplicity enables:
- $49 MSRP (no electronics cost)
- Zero failure modes (nothing electronic to break)
- Ideal for bioluminescent species where any light competes with the natural glow
- The product IS the absence of technology -- just the organism and darkness

---

## Appendix: Variant Comparison Matrix

| Feature | The Void ($79) | Void Core ($299) | Dark Dome ($49) |
|---|---|---|---|
| Dome shell (smoked PC) | Yes | Yes | Yes (or clear option) |
| Matte black base | Yes | Yes | Yes |
| Passive airflow vents | Yes | Yes (+ motorized dampers) | Yes |
| Substrate platform | Yes | Yes | Yes |
| UV-A LEDs (395nm) | 6x | 6x | No |
| Blue fruiting LEDs (450nm) | 6x | 6x | No |
| UV-C sterilization LED | 1x | 1x | No |
| RGB LEDs (WS2812B) | No | 8x | No |
| Safety interlock (magnetic) | Yes | Yes | N/A |
| Mode button | Yes (1 button) | Yes (1 button fallback) | No |
| USB-C power | Yes (5V/1A) | Yes (5V/3A PD) | No |
| 12h light timer | Yes (555 hardware) | Yes (software) | No |
| UV-C auto-shutoff timer | Yes (555 hardware) | Yes (software + hardware) | No |
| Red UV-C indicator LED | Yes | Yes | No |
| Pi Zero W 2 | No | Yes | No |
| BME280 sensor | No | Yes | No |
| CO2 sensor (SCD40) | No | Optional | No |
| Piezo humidifier | No | Yes (100ml reservoir) | No |
| PWM fan (30mm) | No | Yes | No |
| Camera module | No | Yes (5-8MP) | No |
| Wi-Fi / BLE | No | Yes | No |
| App control | No | Yes (Void app) | No |
| Programmable light modes | No | Yes (Deep Space, Aurora, etc.) | No |
| Timelapse | No | Yes | No |
| Estimated power draw | 0.8-1.1W | 5.5W typical | 0W |
| Moving parts | 0 | 3 (fan, humidifier, dampers) | 0 |
| PCB components | 15-25 | 50+ | 0 |

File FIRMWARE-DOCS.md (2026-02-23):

# The Void -- Firmware & Electronics Documentation

> Electronics behavior and programming documentation for all three Void dome variants.
> This document explains how the Void's electronics work, for builders who want to understand, modify, or program their dome.
> For component sourcing, see PARTS-GUIDE.md. For physical assembly, see BUILD-GUIDE.md.

---

## 1. Overview

### Purpose

This document covers the electronic behavior of every Void variant -- from the completely passive Dark Dome to the fully programmable Void Core. Whether you are building a base Void with hardware-only logic or developing software for the Void Core, this is your reference.

### Three Variant Electronics Profiles

| Variant | Electronics | Controller | Complexity |
|---|---|---|---|
| **Dark Dome** | None | None | Zero -- skip to CONTRIBUTING.md for mechanical modifications |
| **The Void** (base) | Discrete components + optional ATtiny85 | Hardware logic (555 timers) or ATtiny85 | Low -- mostly hardware, minimal or no firmware |
| **Void Core** | Full smart electronics | Raspberry Pi Zero W 2 | High -- Python control daemon, sensors, Wi-Fi, app |

### How This Document is Organized

- **Section 2** covers the base Void's hardware-only logic -- no microcontroller required
- **Section 3** covers the optional ATtiny85 microcontroller upgrade for the base Void
- **Section 4** covers the Void Core's Raspberry Pi Zero W 2 software architecture
- **Section 5** confirms the Dark Dome has zero electronics

If you are building a base Void, read Sections 2 and (optionally) 3. If you are contributing to Void Core development, read Section 4. If you are building a Dark Dome, Section 5 is all you need.

---

## 2. Base Void -- Hardware Logic

The base Void uses no microcontroller. All behavior is implemented with discrete components and hardware timing circuits. This means fewer failure modes, lower cost, and zero firmware to maintain.

### 2.1 Circuit Description

Every component in the base Void serves a specific purpose. Here is what each one does and why it is there.

**USB-C PD Sink IC (CH224K)**
Negotiates 5V power from any USB-C source. This tiny IC (SOT-23 package) ensures the Void receives a stable 5V supply from any standard USB charger. It handles the USB-C Power Delivery handshake so you do not need a specific charger -- any phone charger rated 5V/1A or higher works.

**LED Driver (PT4115)**
Constant-current driver that powers the UV-A and Blue LED strings. The PT4115 delivers a fixed 20mA per LED regardless of voltage fluctuations, protecting the LEDs from overcurrent damage and ensuring consistent brightness. It drives two strings of 6 LEDs each (UV-A string and Blue string).

**555 Timer #1 -- 12-Hour Light Cycle**
Configured in astable mode, this timer alternates the lights on a 12-hour on / 12-hour off cycle. This matches the natural fruiting light schedule required by all target mushroom species. The timer enables and disables the LED driver IC, so both UV-A and Blue LEDs follow the same cycle.

**555 Timer #2 -- 15-Minute UV-C Auto-Shutoff**
Configured in monostable mode, this timer limits every UV-C sterilization cycle to exactly 15 minutes. When triggered, it outputs a single 15-minute pulse that powers the UV-C LED. After 15 minutes, it automatically shuts off -- regardless of button state, reed switch state, or anything else. This is a hardware safety guarantee.

**Reed Switch -- Dome Presence Detection**
A normally-open glass reed switch positioned in the base near the dome seating rim. When the dome's embedded neodymium magnet is within 5mm, the reed switch closes and completes the UV-C power circuit. When the dome is removed, the switch opens and UV-C power is physically cut. This is the UV-C safety interlock.

**Mode Button**
A 12mm waterproof tactile switch on the base exterior. Tap to cycle through the four light modes. Press and hold for 3 seconds to trigger a UV-C sterilization cycle. The 3-second hold is detected by an RC delay circuit that prevents accidental UV-C activation from brief taps.

### 2.2 Wiring Architecture

```
USB-C port
    |
    v
[USB-C PD Sink IC (CH224K)] --> 5V rail
    |
    +---> [LED Driver (PT4115)] ---> UV-A LED string (6x series, 395nm)
    |         |
    |         +--------------------> Blue LED string (6x series, 450nm)
    |
    +---> [555 Timer #1] ---> 12h cycle control (enables/disables LED driver)
    |
    +---> [Button] ---> [Mode logic] ---> LED driver enable/channel select
    |                        |
    |                        +---> [3-sec hold detect (RC)] ---> UV-C trigger
    |
    +---> [Reed switch] ---> [555 Timer #2] ---> UV-C LED (275nm)
    |                                             (interlock IN SERIES)
    |
    +---> [Red indicator LED] (wired in parallel with UV-C power)
```

**Key wiring rules:**
- The reed switch is wired **in series** with the UV-C LED power line. UV-C physically cannot receive power without the dome magnet closing the reed switch.
- The red indicator LED is wired in parallel with the UV-C power line. It lights whenever UV-C is active, warning users not to remove the dome.
- Both 555 timers and the LED driver operate from the single 5V rail supplied through USB-C.
- All components fit on a single 2-layer PCB, 50mm x 30mm.

### 2.3 Light Modes

The base Void has five operating modes, cycled with the physical button.

| Mode | UV-A (395nm) | Blue (450nm) | UV-C (275nm) | Trigger |
|---|---|---|---|---|
| 1. Void Glow | ON | ON | OFF | Button tap (default at power-on) |
| 2. UV Only | ON | OFF | OFF | Button tap |
| 3. Blue Only | OFF | ON | OFF | Button tap |
| 4. Off | OFF | OFF | OFF | Button tap |
| 5. Sterilize | OFF | OFF | ON (15 min) | Button hold 3 seconds (dome must be seated) |

**Mode cycling behavior:**
- Tap the button to advance: 1 -> 2 -> 3 -> 4 -> 1 (loops back)
- The 12-hour timer applies to modes 1-3: lights auto-off after 12 hours, auto-on after 12 hours of darkness
- Mode 4 (Off) overrides the timer -- lights stay off until the user taps again
- Mode 5 (Sterilize) is independent of the light cycle timer; it runs for exactly 15 minutes and then stops
- UV-A/Blue and UV-C are never on simultaneously. UV-C only runs between grows with the dome sealed and grow lights off.

### 2.4 555 Timer Configurations

#### 12-Hour Timer (Astable Mode)

The first NE555 timer generates a 12-hour on / 12-hour off square wave that controls the LED driver.

**Astable mode formula:**

```
T_high = 0.693 x (R1 + R2) x C
T_low  = 0.693 x R2 x C
Total period = T_high + T_low
```

For a 24-hour period (12h on, 12h off):
- Target: T_high = T_low = 43,200 seconds (12 hours)
- Using a large electrolytic capacitor (e.g., 1000uF) and high-value resistors:
  - R1 = 1k ohm (small compared to R2 to get ~50% duty cycle)
  - R2 = 62.4M ohm (achieved with series resistor network)
  - C = 1000uF

**Practical note:** Achieving a precise 12-hour period with a 555 timer and passive components is challenging due to component tolerances. Real-world electrolytic capacitors have +/-20% tolerance, and mega-ohm resistors drift with temperature. Builders should expect the cycle to vary between 10-14 hours and may need to adjust R2 to fine-tune the period. Using a CMOS variant (LMC555) reduces current draw and improves timing stability.

**Alternative approach:** If precise 12-hour timing is important, use the ATtiny85 option (Section 3), which implements timing in software with crystal-accurate precision.

#### 15-Minute UV-C Timer (Monostable Mode)

The second NE555 timer generates a single 15-minute pulse when triggered.

**Monostable mode formula:**

```
T_pulse = 1.1 x R x C
```

For a 15-minute (900-second) pulse:
- R = 8.2M ohm
- C = 100uF
- T_pulse = 1.1 x 8,200,000 x 0.0001 = 902 seconds (~15 minutes)

**Trigger mechanism:** When the user holds the mode button for 3 seconds, an RC delay circuit (separate from the timer) pulls the 555 trigger pin (pin 2) low, starting the monostable pulse. A brief tap does not charge the RC circuit enough to reach the trigger threshold, preventing accidental activation.

**Auto-shutoff guarantee:** After the pulse duration, the 555 output goes low and UV-C power is cut. The timer must be re-triggered (another 3-second hold) to start a new cycle. There is no way for UV-C to run continuously -- the hardware enforces the time limit.

### 2.5 UV-C Safety Interlock -- CRITICAL

```
===========================================================================
  SAFETY: UV-C RADIATION HAZARD

  The UV-C LED (275nm) emits germicidal ultraviolet radiation that is
  harmful to eyes and skin. The dose inside the dome (90-180 mJ/cm2)
  is 15-30x the ACGIH 8-hour exposure limit for humans.

  - NEVER look directly at the UV-C LED when powered
  - ALWAYS ensure the dome is fully seated during sterilization
  - The hardware interlock prevents UV-C from activating without the
    dome, but you MUST verify it works before first use (see below)
  - The red indicator LED on the base lights during UV-C -- if it is
    on, do NOT remove the dome
  - If the interlock fails, IMMEDIATELY disconnect USB power
===========================================================================
```

**How the interlock works:**

The reed switch is wired **in series** with the UV-C LED power line. This is not a software check -- it is a physical circuit break. The UV-C LED's power path is:

```
5V rail --> [555 Timer #2 output] --> [Reed switch] --> [UV-C LED] --> GND
```

If the reed switch is open (dome removed), the circuit is broken and no current can flow to the UV-C LED. Period. This works even if:
- The 555 timer is stuck in the "on" state
- The button is held down permanently
- There is no microcontroller (base Void has none)
- Any other component has failed

**The dome magnet must be within 5mm of the reed switch for it to close.** The 6mm x 2mm neodymium disc magnet is embedded in the dome's seating lip, and the reed switch is positioned in the base rim directly below it.

**Safety features summary:**

| Feature | Type | How It Works |
|---|---|---|
| Reed switch in series with UV-C power | Hardware interlock | Dome removal physically cuts UV-C power |
| 555 timer auto-shutoff (15 min) | Hardware timer | UV-C cannot run longer than 15 minutes |
| 3-second button hold required | RC delay circuit | Prevents accidental activation from button taps |
| Red indicator LED | Visual warning | Lights during entire UV-C cycle |
| Polycarbonate/PETG dome | Radiation enclosure | Dome material blocks 100% of UV-C below 300nm |
| Warning label on base | Physical warning | "CAUTION: UV-C germicidal light" |

**Interlock test procedure (mandatory before first use):**

1. Seat the dome on the base and connect USB power
2. Press and hold the mode button for 3 seconds -- the red LED should light
3. While the red LED is on, carefully lift the dome off the base
4. The red LED should immediately turn off (UV-C power cut)
5. Replace the dome -- UV-C should NOT restart (requires new 3-second hold)

**If the interlock fails** (red LED stays on with dome removed): disconnect power immediately. Check reed switch position, wiring, and magnet placement. See BUILD-GUIDE.md troubleshooting section.

### 2.6 Power Budget

All components operate from a single 5V USB rail.

| Component | Voltage | Current (typ) | Current (max) | Power (typ) | Power (max) |
|---|---|---|---|---|---|
| UV-A LEDs (6x 395nm) | 3.2V via 5V | 120mA | 150mA | 0.40W | 0.50W |
| Blue LEDs (6x 450nm) | 3.0V via 5V | 120mA | 150mA | 0.36W | 0.45W |
| LED driver IC (PT4115) | 5V | 10mA | 15mA | 0.05W | 0.08W |
| 555 timer ICs (x2) | 5V | 2mA | 4mA | 0.01W | 0.02W |
| UV-C LED (when active) | 6.5V via 5V boost | 250mA | 350mA | 1.25W | 1.75W |
| Red indicator LED | 5V | 10mA | 15mA | 0.05W | 0.08W |
| USB-C PD sink IC | 5V | 1mA | 2mA | 0.01W | 0.01W |
| Button + reed switch | -- | negligible | negligible | -- | -- |
| **TOTAL (normal grow, lights on)** | | **~253mA** | **~321mA** | **~0.83W** | **~1.05W** |
| **TOTAL (UV-C sterilize)** | | **~263mA** | **~371mA** | **~1.32W** | **~1.85W** |

**Key takeaways:**
- Normal growing mode draws under 1.1W -- well within any USB charger's capability
- Even during UV-C sterilization, total draw is under 2W
- The base Void stays comfortably under the USB 2.0 500mA / 2.5W limit
- UV-A/Blue and UV-C are never on simultaneously, so the real peak is UV-C + red indicator (~1.3W)

### 2.7 Power States

| State | Components Active | Power Draw | Duration |
|---|---|---|---|
| **Off** | None (USB disconnected or mode 4) | 0W | -- |
| **Standby** | 555 timer only (during 12h dark period) | <0.01W | 12 hours |
| **Growing (lights on)** | UV-A + Blue LEDs + LED driver + timer | ~0.8-1.1W | 12 hours |
| **Sterilizing** | UV-C LED + red indicator + timer | ~1.3W | 15 minutes |

---

## 3. Base Void -- ATtiny85 Firmware (Optional)

The ATtiny85 is an optional upgrade that replaces the discrete timing and mode logic with a single 8-pin microcontroller. It is not required for a functional Void, but it adds useful features.

### 3.1 When to Use the ATtiny85

**The ATtiny85 adds:**
- **Mode memory** -- remembers the last selected light mode after power cycle (stored in EEPROM)
- **Simpler button-hold detection** -- replaces the discrete RC delay circuit with firmware debouncing
- **Software timing** -- replaces both 555 timers with more accurate software timers
- **Reduced component count** -- eliminates 2x NE555 ICs and their associated passive components

**Cost:** $0.50-1.00 additional (ATtiny85 IC)

**Trade-off:** The ATtiny85 introduces a software dependency. The 555-based design is purely hardware and has zero firmware to fail. Choose based on whether mode memory and simplified wiring are worth the added complexity.

**Total firmware size:** ~500 bytes (fits easily in the ATtiny85's 8KB flash)

### 3.2 ATtiny85 Pin Assignments

The ATtiny85 has 6 I/O pins (PB0-PB5, where PB5 is shared with RESET).

| Pin | ATtiny85 Pin | Function | Direction | Notes |
|---|---|---|---|---|
| 1 | PB5 / RESET | Reset (not used as I/O) | -- | Leave as reset; needed for ISP programming |
| 2 | PB3 | Button input | Input (pull-up) | 12mm tactile switch; internal pull-up enabled |
| 3 | PB4 | Reed switch input | Input (pull-up) | Normally-open; reads HIGH when dome is removed |
| 4 | GND | Ground | -- | -- |
| 5 | PB0 | UV-A LED string enable | Output | HIGH = UV-A LEDs on via LED driver |
| 6 | PB1 | Blue LED string enable | Output | HIGH = Blue LEDs on via LED driver |
| 7 | PB2 | UV-C trigger | Output | HIGH = UV-C LED on (still gated by reed switch in hardware) |
| 8 | VCC | 5V power | -- | -- |

**Note on PB5/RESET:** PB5 is not used as a general I/O pin because repurposing it as I/O disables ISP programming. The red indicator LED is wired in parallel with the UV-C power line (hardware), not controlled by the ATtiny85.

**Critical safety note:** Even with the ATtiny85, the reed switch remains wired **in series** with the UV-C LED power line. The ATtiny85 checks the reed switch state in software as an additional safety layer, but the hardware interlock is the primary safety mechanism. If the firmware crashes or hangs, the hardware interlock still prevents UV-C from activating without the dome.

### 3.3 Firmware Behavior (Pseudocode)

The following pseudocode describes the complete ATtiny85 firmware. This is a specification, not implementation -- actual C code will be released separately.

```
CONSTANTS:
    LIGHT_CYCLE_MS     = 43,200,000    // 12 hours in milliseconds
    UVC_TIMEOUT_MS     = 900,000       // 15 minutes in milliseconds
    BUTTON_HOLD_MS     = 3,000         // 3-second hold threshold
    DEBOUNCE_MS        = 50            // Button debounce time
    EEPROM_MODE_ADDR   = 0             // EEPROM address for stored mode

VARIABLES:
    current_mode       = 1             // 1=Void Glow, 2=UV Only, 3=Blue Only, 4=Off
    uvc_active         = false
    uvc_start_time     = 0
    cycle_timer        = 0
    lights_on          = true          // Current phase of 12h cycle

// ===== STARTUP =====
FUNCTION setup():
    configure PB0 (UV-A) as OUTPUT, set LOW
    configure PB1 (Blue) as OUTPUT, set LOW
    configure PB2 (UV-C trigger) as OUTPUT, set LOW
    configure PB3 (Button) as INPUT with internal PULL-UP
    configure PB4 (Reed switch) as INPUT with internal PULL-UP

    // Read last mode from EEPROM
    stored_mode = EEPROM.read(EEPROM_MODE_ADDR)
    IF stored_mode >= 1 AND stored_mode <= 4:
        current_mode = stored_mode
    ELSE:
        current_mode = 1    // Default to Void Glow

    apply_mode(current_mode)
    cycle_timer = millis()

// ===== MAIN LOOP =====
FUNCTION loop():
    // --- Handle 12-hour light cycle ---
    IF millis() - cycle_timer >= LIGHT_CYCLE_MS:
        lights_on = NOT lights_on
        cycle_timer = millis()
        IF lights_on:
            apply_mode(current_mode)
        ELSE:
            set PB0 LOW    // UV-A off
            set PB1 LOW    // Blue off

    // --- Handle UV-C auto-shutoff ---
    IF uvc_active:
        IF millis() - uvc_start_time >= UVC_TIMEOUT_MS:
            set PB2 LOW        // UV-C trigger off
            uvc_active = false

        // Additional software safety: check reed switch
        IF PB4 reads HIGH:    // Dome removed
            set PB2 LOW        // UV-C trigger off
            uvc_active = false

    // --- Handle button input ---
    IF button_pressed():        // Debounced read of PB3
        hold_time = measure_hold_duration()

        IF hold_time >= BUTTON_HOLD_MS:
            // Long press: start UV-C cycle
            start_uvc_cycle()
        ELSE:
            // Short press: cycle light mode
            current_mode = current_mode + 1
            IF current_mode > 4:
                current_mode = 1
            EEPROM.write(EEPROM_MODE_ADDR, current_mode)
            apply_mode(current_mode)

// ===== APPLY LIGHT MODE =====
FUNCTION apply_mode(mode):
    IF NOT lights_on AND mode != 4:
        RETURN    // In dark phase of 12h cycle; don't turn on lights

    SWITCH mode:
        CASE 1 (Void Glow):
            set PB0 HIGH    // UV-A on
            set PB1 HIGH    // Blue on
        CASE 2 (UV Only):
            set PB0 HIGH    // UV-A on
            set PB1 LOW     // Blue off
        CASE 3 (Blue Only):
            set PB0 LOW     // UV-A off
            set PB1 HIGH    // Blue on
        CASE 4 (Off):
            set PB0 LOW     // UV-A off
            set PB1 LOW     // Blue off

// ===== START UV-C CYCLE =====
FUNCTION start_uvc_cycle():
    // Check reed switch (software safety -- hardware interlock is primary)
    IF PB4 reads HIGH:        // Dome not detected
        RETURN                // Refuse to start UV-C

    // Turn off grow lights during sterilization
    set PB0 LOW
    set PB1 LOW

    // Start UV-C
    set PB2 HIGH              // UV-C trigger on
    uvc_active = true
    uvc_start_time = millis()
```

### 3.4 Programming the ATtiny85

**Required hardware:**
- USBasp programmer ($3-5 from AliExpress) **or** an Arduino Uno used as ISP programmer ("Arduino as ISP")
- 6 jumper wires for ISP connection
- Breadboard (optional but helpful)

**Fuse settings:**
- CKSEL: 8MHz internal oscillator (no external crystal needed)
- SUT: 65ms startup delay
- CKDIV8: disabled (run at full 8MHz, not divided to 1MHz)
- BOD: 2.7V brownout detection enabled (prevents corruption during power fluctuation)

**Fuse byte values:** Low: 0xE2, High: 0xDF, Extended: 0xFF

**Recommended development environment:**
- Arduino IDE with the "ATtiny" board package by David A. Mellis (or SpenceKonde's ATTinyCore)
- Board: "ATtiny85"
- Clock: "Internal 8 MHz"
- Programmer: "USBasp" or "Arduino as ISP"

**Flash procedure:**
1. Connect ISP programmer to ATtiny85: VCC, GND, MOSI (PB0/pin 5), MISO (PB1/pin 6), SCK (PB2/pin 7), RESET (PB5/pin 1)
2. In Arduino IDE, select Tools > Board > ATtiny85, Clock > Internal 8 MHz
3. Select Tools > Programmer > USBasp (or Arduino as ISP)
4. Click Tools > Burn Bootloader (sets fuse bits -- do this once)
5. Open the firmware sketch and click Upload

**Note:** The ATtiny85 firmware is not included in Void Blueprints v1.0. The pseudocode above is the specification. Community contributors are welcome to implement it -- see CONTRIBUTING.md for how to contribute firmware.

---

## 4. Void Core -- Pi Zero W 2 Software

The Void Core adds a Raspberry Pi Zero W 2 running a Python control daemon. This transforms the Void from a passive hardware device into a fully programmable smart cultivation dome with sensors, active environmental control, timelapse photography, and app connectivity.

**Important:** The Void Core software is NOT included in Void Blueprints v1.0. This section documents the architecture for contributors who want to help build it. The base Void (hardware-only) is the primary open-source release.

### 4.1 Hardware Setup

**Pi Zero W 2 connections:**

| Interface | Connected To | Protocol | Notes |
|---|---|---|---|
| I2C (SDA/SCL) | BME280 sensor | I2C (400kHz) | Temperature + humidity + pressure |
| I2C (SDA/SCL) | SCD40 CO2 sensor | I2C (100kHz) | Optional; shares I2C bus with BME280 |
| GPIO | UV-A LED string enable | Digital output | Same LED ring as base Void |
| GPIO | Blue LED string enable | Digital output | Same LED ring as base Void |
| GPIO | UV-C trigger | Digital output | Still gated by hardware reed switch interlock |
| GPIO | Fan speed control | PWM output | 30mm axial fan, 5V DC |
| GPIO | Humidifier on/off | Digital output | Piezo disc, 20mm, 113 KHz |
| GPIO | Motorized damper #1 | PWM/servo | Intake vent aperture control |
| GPIO | Motorized damper #2 | PWM/servo | Exhaust vent aperture control |
| GPIO | WS2812B data | Single-wire NZR | 8 addressable RGB LEDs |
| CSI | Camera module | Ribbon cable | 5MP or 8MP Pi-compatible module |
| Wi-Fi | Void app | 2.4 GHz | Local network communication |
| BLE | Initial setup | Bluetooth LE | WiFi provisioning |

**Pin mapping (BCM numbering):**

| BCM Pin | Function | Direction |
|---|---|---|
| GPIO 2 (SDA) | I2C data (BME280, SCD40) | Bidirectional |
| GPIO 3 (SCL) | I2C clock (BME280, SCD40) | Output |
| GPIO 4 | UV-A LED string enable | Output |
| GPIO 5 | Blue LED string enable | Output |
| GPIO 6 | UV-C trigger | Output |
| GPIO 12 | Fan PWM | Output (hardware PWM) |
| GPIO 13 | Humidifier enable | Output |
| GPIO 16 | Damper #1 servo PWM | Output |
| GPIO 17 | Damper #2 servo PWM | Output |
| GPIO 18 | WS2812B data | Output |
| GPIO 22 | Reed switch input | Input (pull-up) |
| GPIO 27 | Button input | Input (pull-up) |
| CSI port | Camera module | -- |

**Power requirements:**
- Void Core requires USB-C PD at 5V/3A (15W)
- The Pi Zero W 2 alone draws 300-500mA at 5V
- Total Void Core typical power: ~5.5W; peak (all systems active): ~10W
- Standard USB 2.0 (500mA/2.5W) is NOT sufficient for Void Core

### 4.2 Software Architecture

**Operating system:** Raspberry Pi OS Lite (headless, no desktop environment)

**Control daemon:** A Python application running as a systemd service. It starts automatically on boot and manages all Void Core hardware.

**Module structure:**

```
void-core/
    |-- voidcore.py              # Main daemon entry point
    |-- sensor_reader.py         # BME280 / SCD40 polling
    |-- climate_controller.py    # PID loop for humidity and CO2
    |-- light_controller.py      # LED modes, 12h cycle, UV-C control
    |-- camera_controller.py     # Timelapse capture
    |-- web_server.py            # Flask/FastAPI local API for Void app
    |-- wifi_setup.py            # BLE-based WiFi configuration
    |-- config.py                # User-configurable settings
    |-- requirements.txt         # Python dependencies
```

**Module descriptions:**

| Module | Responsibility | Poll Interval |
|---|---|---|
| `sensor_reader.py` | Reads BME280 (temp, humidity, pressure) and SCD40 (CO2) via I2C | Every 30 seconds |
| `climate_controller.py` | PID control loop -- adjusts fan speed, humidifier duty cycle, and damper position based on sensor readings | Every 30 seconds (tied to sensor reads) |
| `light_controller.py` | Manages all LED modes (base modes + Void Core modes like Deep Space, Aurora, Music Sync), 12-hour cycle timer, and UV-C sterilization control | Event-driven + 12h timer |
| `camera_controller.py` | Captures timelapse images at configurable intervals and stores them on the microSD card | Configurable (default: every 15 minutes) |
| `web_server.py` | Exposes a local REST API for the Void app to read sensor data, change modes, and adjust settings | Always running (HTTP server) |
| `wifi_setup.py` | Handles initial WiFi provisioning via BLE -- the user configures WiFi credentials from their phone without needing a keyboard or monitor | Runs on first boot or when WiFi is unconfigured |

### 4.3 Control Logic

#### Humidity PID Controller

| Parameter | Value | Notes |
|---|---|---|
| Setpoint | 88% RH | Default; user-adjustable via app (80-95% range) |
| Deadband | +/- 2% RH | No action taken within 86-90% RH |
| Sensor | BME280 | +/- 3% RH accuracy |
| Actuator | Piezo humidifier disc (20mm, 113 KHz) | PWM duty cycle proportional to humidity deficit |
| Secondary actuator | 30mm fan (brief speed increase) | Used to vent excess humidity if RH > setpoint + 2% |

**Control behavior:**
1. Read humidity from BME280 every 30 seconds
2. If RH < (setpoint - 2%): activate humidifier at duty cycle proportional to deficit
3. If RH > (setpoint + 2%): pause humidifier; briefly increase fan speed to vent excess
4. If RH is within deadband: no action (steady state)

#### CO2 Management

| CO2 Level | Action |
|---|---|
| < 600 ppm | Normal -- fan at baseline speed |
| 600-1000 ppm | Fan speed increases proportionally |
| > 1000 ppm | Alarm -- maximum fan speed, app notification |
| > 2000 ppm (Reishi antler mode) | Intentional -- close dampers to accumulate CO2 for antler growth |

**Reishi antler mode:** When enabled via the app, the climate controller closes the motorized dampers to restrict airflow, allowing CO2 to accumulate above 2000 ppm. This triggers reishi to produce antler formations instead of conks. The fan runs at minimum speed for air circulation only, not exchange.

#### Void Core Light Modes

In addition to the four base modes (Void Glow, UV Only, Blue Only, Off), Void Core adds:

| Mode | Description | LEDs Used |
|---|---|---|
| Deep Space | Slow UV-A pulse with deep blue undertone | UV-A + Blue (PWM dimming) |
| Bioluminescence | Minimal light for Panellus viewing | Blue at 5% duty cycle |
| Aurora | Slow color sweep across UV-A intensity levels | UV-A (PWM sweep) |
| Blacklight | Maximum UV-A intensity | UV-A at 100% |
| Music Sync | Beat-reactive UV-A + Blue flashing | UV-A + Blue (microphone input) |
| Custom | User-defined intensity and timing per channel | All channels, app-configured |

The WS2812B RGB ring (8 LEDs) provides additional color accent capabilities for Deep Space, Aurora, and Music Sync modes.

### 4.4 API Endpoints (for Void App)

The Void Core exposes a local REST API via Flask or FastAPI, accessible over WiFi.

| Method | Endpoint | Description | Request Body | Response |
|---|---|---|---|---|
| GET | `/status` | Current sensor readings, mode, uptime | -- | `{ temp, humidity, co2, mode, uptime, uvc_active }` |
| POST | `/mode` | Set light mode | `{ mode: "void_glow" }` | `{ success: true, mode: "void_glow" }` |
| POST | `/settings` | Update control setpoints | `{ humidity_setpoint, co2_target, light_schedule }` | `{ success: true, settings: {...} }` |
| GET | `/timelapse` | List captured timelapse images | -- | `{ images: [{ filename, timestamp, size }] }` |
| POST | `/sterilize` | Trigger UV-C sterilization cycle | `{ confirm: true }` | `{ success: true, duration_minutes: 15 }` |
| GET | `/config` | Read current configuration | -- | `{ all current settings }` |
| POST | `/wifi` | Update WiFi credentials | `{ ssid, password }` | `{ success: true }` |

**Safety note on `/sterilize`:** The API requires `confirm: true` in the request body as an additional confirmation step. This is a software safety layer on top of the hardware reed switch interlock. The hardware interlock is the primary safety mechanism -- even if the API is called maliciously, UV-C cannot activate without the dome in place.

### 4.5 Void Core Power Budget

| Component | Voltage | Current (typ) | Power (typ) |
|---|---|---|---|
| Base Void components | 5V | 253mA | 0.83W |
| Raspberry Pi Zero W 2 | 5V | 300mA | 1.50W |
| BME280 sensor | 3.3V | 1mA | 0.003W |
| SCD40 CO2 sensor (optional) | 3.3V | 15mA | 0.05W |
| Piezo humidifier | 5V | 300mA | 1.50W |
| 30mm fan | 5V | 80mA | 0.40W |
| WS2812B RGB ring (8x) | 5V | 160mA | 0.80W |
| Camera module | 3.3V | 50mA | 0.17W |
| Motorized dampers (x2) | 5V | 50mA | 0.25W |
| **TOTAL (typical)** | | **~1,209mA** | **~5.5W** |
| **TOTAL (all active, peak)** | | **~2,123mA** | **~10W** |

### 4.6 Void Core Power States

| State | Components Active | Power Draw | Duration |
|---|---|---|---|
| **Void Core idle** | Pi Zero + sensors (lights in dark period) | ~1.6W | 12 hours |
| **Void Core growing** | Pi + sensors + LEDs + fan + occasional mist | ~5.5W | 12 hours |
| **Void Core peak** | All systems active simultaneously | ~10W | Brief bursts |
| **Void Core sterilizing** | Pi + UV-C + red indicator | ~3.0W | 15-30 minutes |

---

## 5. Dark Dome -- No Electronics

The Dark Dome is the simplest variant. It has **zero electronics**.

### What the Dark Dome Is

- The same physical shell as The Void (8.0" diameter x 10.0" tall)
- Same dome, same base, same substrate platform, same airflow vents
- No PCB, no LEDs, no USB port, no button, no reed switch, no magnet
- No wiring of any kind
- Purely passive cultivation chamber

### What the Dark Dome Is For

The Dark Dome is designed for:
- **Bioluminescent species** (Panellus stipticus) -- any artificial light competes with the natural glow, so the dome provides total darkness
- **Budget builds** -- skip all electronics and just print the enclosure (~$11.50 in filament)
- **Growers who already have lighting** -- use your own LED setup externally

### Electronics Cost

Zero. The Dark Dome costs only the filament to print. Total estimated material cost: ~$11.50 (PETG, ~380g).

### What to Build Instead

If you are building a Dark Dome, skip Sections 2, 3, and 4 of this document entirely. Your build process is:

1. Print the dome, base, platform, and vent caps (see BUILD-GUIDE.md)
2. Install the silicone gasket in the base rim
3. Apply micropore tape to all vents
4. Skip the magnet -- there is no reed switch to trigger
5. Place a substrate block and grow

For community modifications and remix ideas, see CONTRIBUTING.md.

---

*Firmware Documentation version: 1.0*
*Part of the Void Blueprints open-source package.*

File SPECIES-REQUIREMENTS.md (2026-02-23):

# Species Cultivation Requirements & Environment Specifications

> Research compiled for The Void Grows dome design (8" diameter x 10" tall chamber).
> All parameters sourced from university extension programs, mycology research, and established cultivators.
> Uncertainties are flagged explicitly. Do NOT use uncited numbers as authoritative.

---

## 1. Lion's Mane (Hericium erinaceus) -- FLAGSHIP SPECIES

The flagship species included with every dome. Must work perfectly in the 8" x 10" chamber.

### Temperature

| Phase | Range | Optimum | Notes |
|---|---|---|---|
| Colonization | 68-77degF (20-25degC) | 75degF (24degC) | Mycelial growth optimum at 25degC per PMC research (PMC3755240) |
| Fruiting | 60-75degF (16-24degC) | 65-70degF (18-21degC) | Cooler temps produce denser, higher-quality fruiting bodies |

**Sources:** [The Spore Depot](https://thesporedepot.com/growing-hericium-erinaceus/), [Groovy Pigeon Mycology](https://groovypigeonmycology.com/blogs/growing-conditions/lion-s-mane-mushroom-environmental-and-growing-requirements-for-success), [PMC3755240](https://pmc.ncbi.nlm.nih.gov/articles/PMC3755240/)

### Humidity

| Phase | Range | Critical Minimum | Notes |
|---|---|---|---|
| Colonization | 80-90% RH | 75% | Lower humidity acceptable during spawn run if substrate is sealed |
| Fruiting | 85-95% RH | 80% | Below 80% causes browning, stunted spines, and abort |

**Sources:** [BootstrapBee](https://bootstrapbee.com/mushrooms/lions-mane-fruiting-conditions), [Fungi Academy](https://fungiacademy.com/how-to-grow-lions-mane-mushrooms/)

### Fresh Air Exchange (FAE) & CO2

| Parameter | Value | Notes |
|---|---|---|
| CO2 tolerance (fruiting) | 500-800 ppm | Below 800 ppm critical for proper pom-pom morphology |
| CO2 tolerance (colonization) | Up to 5,000+ ppm | High CO2 acceptable during spawn run |
| Air exchange frequency | 5-8 exchanges/hour | High FAE required -- lion's mane is CO2-sensitive |
| CO2 stress symptoms | Short spines, elongated stalk, coral-like branching instead of single pom-pom | Extremely diagnostic -- malformed fruit = too much CO2 |

**CRITICAL NOTE:** Lion's mane is one of the most CO2-sensitive gourmet species. The dome's passive airflow vents must be designed to keep CO2 well below 1,000 ppm during fruiting. This is the single most important design constraint for the flagship species.

**Sources:** [BootstrapBee](https://bootstrapbee.com/mushrooms/lions-mane-fruiting-conditions), [Atlas Scientific](https://atlas-scientific.com/blog/why-you-need-a-co2-meter-for-growing-mushrooms/), [Liquid Fungi](https://liquidfungi.com/pages/special-considerations-when-growing-lions-mane-mushrooms)

### Light Requirements

| Parameter | Value | Notes |
|---|---|---|
| Wavelength | 430-470nm (blue spectrum) | Blue light photoreceptors trigger pinning and development |
| Intensity | 200-500 lux | Gentle indirect light preferred; 200-400 lux optimal range |
| Duration | 12h on / 12h off | Diurnal cycle triggers pinning genes |
| Color temperature | 5000-6500K | Cool white / daylight spectrum |

**Sources:** [Active Grow LED](https://activegrowled.com/pages/why-blue-light-is-best-for-growing-mushrooms), [Mushroom Enthusiast](https://www.mushroomenthusiast.com/all-about-mushroom-grow-lights/)

### Substrate Preferences

| Substrate | Suitability | Notes |
|---|---|---|
| Master's Mix (50/50 hardwood sawdust + soy hulls) | **Best** | Produces largest, densest fruiting bodies |
| Hardwood sawdust + 10-20% wheat bran | Excellent | Traditional commercial substrate |
| Hardwood sawdust + 10-20% rice bran | Excellent | PMC research confirms optimal mycelial growth |
| Straw | Poor | Not recommended for lion's mane |

Hydration: 60-65% moisture content. Must be sterilized (pressure cook 15 PSI, 2+ hours).

**Sources:** [GroCycle (Master's Mix)](https://grocycle.com/what-is-masters-mix/), [Mushroom Substrate](https://www.mushroomsubstrate.com/blogs/mushroom-substrate-blog/lions-mane-mushroom-substrate-recipe), [PMC3755240](https://pmc.ncbi.nlm.nih.gov/articles/PMC3755240/)

### Growth Timeline

| Stage | Duration | Notes |
|---|---|---|
| Colonization (spawn run) | 14-21 days | At 75degF; full white mycelium coverage |
| Primordia formation (pinning) | 3-7 days | Triggered by fresh air, light, and temperature drop |
| Fruiting body development | 5-10 days | Spines elongate; harvest when spines begin to droop |
| Total (inoculation to harvest) | 22-38 days | Fastest of the non-oyster gourmet species |
| Flushes | 2-3 | Subsequent flushes smaller; soak block between flushes |

**Sources:** [Lykyn](https://lykyn.com/blogs/news/lions-mane-mushroom-growth-stages), [The Spore Depot](https://thesporedepot.com/growing-hericium-erinaceus/)

### Dome Compatibility Notes (8" x 10" Chamber)

- **Size:** Lion's mane fruiting bodies can reach 4-8" diameter in optimal conditions. The 8" dome diameter should accommodate a single fruiting body well, but may constrain very large specimens.
- **CO2 is the critical constraint.** The small chamber volume (~400 cubic inches) will accumulate CO2 quickly from a respiring substrate block. Passive vents must be carefully sized and positioned.
- **Humidity retention:** The enclosed dome should maintain humidity well. Risk of over-humidification (condensation dripping on fruit body) rather than under-humidification.
- **Substrate block size:** A standard 5 lb fruiting block will NOT fit in the dome. Void Packs must be custom-sized -- likely 1-2 lb blocks optimized for the chamber volume.
- **Recommended as included species:** Yes -- flagship. Chamber must be optimized for this species first.

---

## 2. Blue Oyster (Pleurotus ostreatus var. columbinus)

The most forgiving species. Beginner-friendly and fast-growing.

### Temperature

| Phase | Range | Optimum | Notes |
|---|---|---|---|
| Colonization | 65-75degF (18-24degC) | 75degF (24degC) | Fast colonizer at warm room temp |
| Fruiting | 45-65degF (7-18degC) | 55-60degF (13-16degC) | Cold-loving species; prefers cooler fruiting temps than other oysters |

**NOTE:** Blue oyster's preference for cool fruiting temperatures (45-65degF) is significantly lower than the other target species. This creates a design tension -- the dome may need to accommodate species with very different temperature preferences. Blue oyster will fruit at room temperature but produces smaller, thinner caps with longer stems.

**Sources:** [North Spore](https://northspore.com/blogs/the-black-trumpet/how-to-grow-blue-oyster-mushrooms), [The Spore Depot](https://thesporedepot.com/growing-blue-oyster-mushrooms/), [GroCycle](https://grocycle.com/blue-oyster-mushroom/)

### Humidity

| Phase | Range | Critical Minimum | Notes |
|---|---|---|---|
| Colonization | 80-90% RH | 75% | Substrate in sealed bag; ambient not critical |
| Fruiting | 85-95% RH | 80% | Pins abort below 80%; caps crack and curl |

**Sources:** [The Mushroom Box](https://themushroombox.shop/blogs/the-mushroom-blog/what-you-need-to-know-about-blue-oyster-mushrooms), [GroCycle](https://grocycle.com/how-to-grow-oyster-mushrooms/)

### Fresh Air Exchange (FAE) & CO2

| Parameter | Value | Notes |
|---|---|---|
| CO2 tolerance (fruiting) | < 800 ppm | Very CO2-sensitive; will produce "fuzzy feet" (elongated stems, tiny caps) |
| CO2 tolerance (colonization) | Up to 10,000+ ppm | High CO2 acceptable during spawn run |
| Air exchange frequency | 4-6 exchanges/hour | Slightly less demanding than lion's mane but still needs strong FAE |
| CO2 stress symptoms | Elongated stems, small caps ("fuzzy feet"), spongy texture | The classic sign of insufficient FAE in oyster cultivation |

**Sources:** [Zombie Myco](https://zombiemyco.com/blogs/mushroom-teks/co2-meter-for-mushrooms-do-you-really-need-one), [The Spore Depot](https://thesporedepot.com/growing-blue-oyster-mushrooms/)

### Light Requirements

| Parameter | Value | Notes |
|---|---|---|
| Wavelength | 430-470nm (blue spectrum) | Blue light triggers pinning |
| Intensity | 500-1,000 lux | Moderate indirect light; can tolerate up to 3,000 lux |
| Duration | 12h on / 12h off | Standard diurnal cycle |

**Sources:** [Mobile Mycology](https://www.mobilemycology.com/optimizing-light-intensity-and-spectrum-for-mushroom-cultivation/), [La Mycosphere](https://lamycosphere.com/en-int/blogs/the-future-is-fungi/do-mushrooms-need-light)

### Substrate Preferences

| Substrate | Suitability | Notes |
|---|---|---|
| Straw (pasteurized) | **Best** | Fastest colonization; natural preference |
| Hardwood sawdust + supplements | Excellent | Works well with Master's Mix |
| Coffee grounds (supplemented) | Good | Budget option; higher contamination risk |
| Cardboard | Fair | Slow but works for small-scale |

Straw preparation: hot water pasteurization at 160-170degF (71-77degC) for 1-2 hours.

**Sources:** [North Spore](https://northspore.com/blogs/the-black-trumpet/how-to-grow-blue-oyster-mushrooms), [GroCycle](https://grocycle.com/how-to-grow-oyster-mushrooms/)

### Growth Timeline

| Stage | Duration | Notes |
|---|---|---|
| Colonization (spawn run) | 10-14 days (sawdust), 14-21 days (straw) | Fast colonizer |
| Pinning | 3-5 days | Triggered by FAE, light, and temperature drop |
| Fruiting body development | 5-7 days | Rapid cluster formation |
| Total (inoculation to harvest) | 18-26 days | Among the fastest gourmet species |
| Flushes | 2-4 | Good repeat fruiter |

**Sources:** [EZMushroom](https://ezmushroom.com/grow/how-to-grow-blue-oyster-mushrooms/), [North Spore](https://northspore.com/blogs/the-black-trumpet/how-to-grow-blue-oyster-mushrooms)

### Dome Compatibility Notes (8" x 10" Chamber)

- **Size:** Blue oyster clusters grow laterally from the substrate. Multiple clusters may emerge from a single block. Clusters can reach 4-6" spread.
- **Growth habit:** Oysters grow FROM the substrate surface toward light and air. The dome needs adequate clearance and the substrate block should be positioned so clusters grow upward, not pressed against the dome wall.
- **Temperature concern:** Blue oyster prefers cooler temps (45-65degF for fruiting) than room temperature. At typical indoor temps (68-72degF), expect leggy stems and smaller caps. Still viable but not optimal.
- **FAE sensitivity:** Will show "fuzzy feet" quickly in the small dome volume if vents are insufficient.
- **Recommended as beginner species:** Yes -- extremely forgiving. Even sub-optimal conditions produce some harvest.

---

## 3. Pink Oyster (Pleurotus djamor)

Tropical species with stunning visual appeal. Fast-growing and warm-loving.

### Temperature

| Phase | Range | Optimum | Notes |
|---|---|---|---|
| Colonization | 75-86degF (24-30degC) | 77-80degF (25-27degC) | Warm -- tropical origin |
| Fruiting | 68-86degF (20-30degC) | 75-80degF (24-27degC) | One of the few species that fruits well at warm room temp |

**IMPORTANT:** Pink oyster mycelium dies below 45degF (7degC). Do NOT refrigerate cultures or substrate. This is a critical handling consideration for Void Pack shipping and storage.

**Sources:** [GroCycle](https://grocycle.com/pink-oyster-mushroom/), [Zombie Myco](https://zombiemyco.com/pages/pink-oyster-mushroom-pleurotus-djamor), [Out-Grow](https://www.out-grow.com/blogs/growing-mushrooms/pink-oyster-mushroom-cultivation-guide)

### Humidity

| Phase | Range | Critical Minimum | Notes |
|---|---|---|---|
| Colonization | 80-90% RH | 75% | Sealed substrate bag |
| Fruiting | 85-95% RH | 70% | More tolerant of lower humidity than some species |

**Sources:** [Mushroom Farm Supplies](https://mushroomfarmsupplies.com.au/pink-oyster-mushroom-fruiting-conditions/), [GroCycle](https://grocycle.com/pink-oyster-mushroom/)

### Fresh Air Exchange (FAE) & CO2

| Parameter | Value | Notes |
|---|---|---|
| CO2 tolerance (fruiting) | < 1,000 ppm | Slightly more CO2-tolerant than blue oyster |
| Air exchange frequency | 4-6 exchanges/hour | Standard oyster FAE requirements |
| CO2 stress symptoms | Elongated stems, small caps, leggy growth | Same as other oyster species |

**Sources:** [Mushroom Farm Supplies](https://mushroomfarmsupplies.com.au/pink-oyster-mushroom-fruiting-conditions/), [Agripie](https://www.agripie.com/post/how-to-grow-pleurotus-djamor-mushrooms-effectively)

### Light Requirements

| Parameter | Value | Notes |
|---|---|---|
| Wavelength | 430-470nm (blue spectrum) | Same photoreceptor response as other Pleurotus |
| Intensity | 500-1,000 lux | Diffused, indirect light |
| Duration | 12h on / 12h off | Standard diurnal cycle |

**Sources:** [Active Grow LED](https://activegrowled.com/pages/why-blue-light-is-best-for-growing-mushrooms), [Mobile Mycology](https://www.mobilemycology.com/optimizing-light-intensity-and-spectrum-for-mushroom-cultivation/)

### Substrate Preferences

| Substrate | Suitability | Notes |
|---|---|---|
| Straw (pasteurized) | **Best** | Fastest colonization for this species |
| Hardwood sawdust + supplements | Good | Works well but slightly slower |
| Coffee grounds | Good | Suitable for small-scale |
| Agricultural waste (corn cob, cotton seed hulls) | Good | Tropical species is adaptable |

**Sources:** [GroCycle](https://grocycle.com/pink-oyster-mushroom/), [ResearchGate](https://www.researchgate.net/publication/328630516_Cultivation_of_pink_Oyster_mushroom_Pleurotus_djamor_var_roseus_on_various_agro-residues_by_low_cost_technique)

### Growth Timeline

| Stage | Duration | Notes |
|---|---|---|
| Colonization (spawn run) | 10-14 days | Fastest oyster variety; may pin before full colonization |
| Pinning | 3-5 days | Can begin as early as day 9 from inoculation |
| Fruiting body development | 4-7 days | Very fast; mature in 4-5 days under optimal conditions |
| Total (inoculation to harvest) | 14-21 days | Fastest of all target species |
| Flushes | 2-3 | Quick successive flushes |

**Sources:** [GroCycle](https://grocycle.com/pink-oyster-mushroom/), [The Spore Depot](https://thesporedepot.com/growing-pink-oyster-mushrooms/)

### Dome Compatibility Notes (8" x 10" Chamber)

- **Visual appeal:** Vibrant coral-pink color makes this species particularly striking under UV-A lighting. Key visual species for marketing.
- **Temperature fit:** Fruits well at room temperature (68-80degF), making it ideal for an unheated desktop dome.
- **Speed:** Fastest species in the lineup -- good for first-time users who want quick results.
- **Shipping constraint:** Cannot be exposed to temperatures below 45degF. Void Pack shipping must account for cold weather.
- **Cluster size:** Pink oyster clusters are typically smaller than blue oyster, fitting well within the dome.
- **Short shelf life:** Fruits deteriorate quickly after harvest (1-2 days). Encourage users to harvest and consume immediately.

---

## 4. Shiitake (Lentinula edodes)

Culinary staple with more complex cultivation requirements. Rewards patience.

### Temperature

| Phase | Range | Optimum | Notes |
|---|---|---|---|
| Colonization | 68-80degF (20-27degC) | 75degF (24degC) | Standard warm colonization |
| Browning (maturation) | 60-70degF (16-21degC) | 65degF (18degC) | Unique stage: block turns brown over 4-8 weeks |
| Fruiting initiation | Cold shock: 35-50degF (2-10degC) for 12-24h | 40degF (4degC) | Cold shock triggers pinning; refrigerate block |
| Fruiting | 55-70degF (13-21degC) | 60-65degF (16-18degC) | Cooler fruiting produces higher quality caps |

**NOTE:** Shiitake has a unique "browning" stage between colonization and fruiting. The block must turn 75%+ brown (8-12 weeks after inoculation) before fruiting is initiated. This is NOT contamination -- it is a melanized protective layer. The cold shock requirement may be difficult to achieve in a passive desktop dome without user intervention (e.g., placing block in refrigerator before returning to dome).

**Sources:** [FreshCap](https://learn.freshcap.com/growing/growing-shiitake-mushrooms/), [GroCycle](https://grocycle.com/how-to-grow-shiitake-mushrooms/), [Unicorn Bags](https://unicornbags.com/cultivation/lentinula-edodes/)

### Humidity

| Phase | Range | Critical Minimum | Notes |
|---|---|---|---|
| Colonization | 90-100% RH | 85% | Sealed bag; high humidity for spawn run |
| Browning | 70-80% RH | 60% | Reduced humidity during maturation |
| Fruiting (early) | 85-95% RH | 80% | High humidity during pin development |
| Fruiting (late) | 60-80% RH | 55% | Reduce humidity as caps mature to prevent waterlogging |

**Sources:** [Unicorn Bags](https://unicornbags.com/cultivation/lentinula-edodes/), [Mushroom Farm Supplies](https://mushroomfarmsupplies.com.au/shiitake-3782-fruiting-conditions/)

### Fresh Air Exchange (FAE) & CO2

| Parameter | Value | Notes |
|---|---|---|
| CO2 tolerance (fruiting) | < 1,000 ppm (optimal 600-800 ppm) | Moderate sensitivity |
| CO2 tolerance (colonization) | 10,000+ ppm | Minimal air exchange during spawn run |
| Air exchange frequency | 4-8 exchanges/hour during fruiting | Standard range |
| CO2 stress symptoms | Elongated stems, thin caps | Less dramatic than oyster species |

**NOTE:** Shiitake is more CO2-tolerant than oyster species during fruiting. It will produce acceptable-looking fruits at slightly elevated CO2 levels, though quality improves with better ventilation.

**Sources:** [Unicorn Bags](https://unicornbags.com/cultivation/lentinula-edodes/), [CO2 Meter](https://www.co2meter.com/blogs/news/co2-mushroom-farming)

### Light Requirements

| Parameter | Value | Notes |
|---|---|---|
| Wavelength | 430-470nm (blue spectrum) | Blue light important for cap formation |
| Intensity | 500-2,000 lux | Higher light requirements than oyster species |
| Duration | 12h on / 12h off | Standard diurnal cycle |

**NOTE:** Shiitake has among the highest light requirements of the target species. The dome's UV-A LEDs may not provide sufficient blue-spectrum light for optimal cap development. Consider supplemental white/blue LEDs or ensure UV-A output partially overlaps the blue range.

**Sources:** [Unicorn Bags](https://unicornbags.com/cultivation/lentinula-edodes/), [Active Grow LED](https://activegrowled.com/pages/why-blue-light-is-best-for-growing-mushrooms)

### Substrate Preferences

| Substrate | Suitability | Notes |
|---|---|---|
| Hardwood sawdust + 10-20% wheat bran | **Best** | Industry standard for indoor shiitake blocks |
| Hardwood sawdust + 10-20% rice bran | Excellent | Common Asian production method |
| Oak logs (outdoor) | Traditional | Not applicable for dome |
| Master's Mix | Good | Works but some growers report odd-looking fruits with high supplementation |

Add 1-3% gypsum (calcium sulfate) for pH buffering. Must be sterilized.

**Sources:** [FreshCap](https://learn.freshcap.com/growing/growing-shiitake-mushrooms/), [Mushroom Substrate](https://www.mushroomsubstrate.com/blogs/mushroom-substrate-blog/how-to-grow-shiitake-mushrooms), [PMC10456065](https://pmc.ncbi.nlm.nih.gov/articles/PMC10456065/)

### Growth Timeline

| Stage | Duration | Notes |
|---|---|---|
| Colonization (spawn run) | 30-45 days | Slower than oyster or lion's mane |
| Browning (maturation) | 30-60 days | Block turns brown; must reach 75%+ brown |
| Cold shock | 12-24 hours | Refrigerate or cold water soak |
| Pinning | 5-7 days | After cold shock + return to fruiting conditions |
| Fruiting body development | 7-14 days | Slower fruit development than oyster |
| Total (inoculation to first harvest) | 75-130 days | Significantly longer than other target species |
| Flushes | 2-4 | Soak block 12-24h between flushes |

**Sources:** [FreshCap](https://learn.freshcap.com/growing/growing-shiitake-mushrooms/), [GroCycle](https://grocycle.com/how-to-grow-shiitake-mushrooms/)

### Dome Compatibility Notes (8" x 10" Chamber)

- **Long timeline:** 2.5-4+ months from inoculation to first harvest. This is a patience species. Marketing must set expectations clearly.
- **Cold shock required:** Users must remove the block from the dome, refrigerate it for 12-24 hours, then return it. This is an active step that breaks the "set it and forget it" simplicity of the dome.
- **Browning stage:** The block will look brown and potentially alarming to beginners for weeks. Documentation must explain this is normal and necessary.
- **Cap size:** Individual shiitake caps are 2-4" diameter, fitting well within the dome.
- **Void Pack design:** Shiitake Void Packs should be pre-colonized AND pre-browned (ready for cold shock and fruiting). This skips the 2-3 month wait and makes the dome experience much more practical. Ship the block already at the browning stage.
- **Higher light needs:** May require supplemental blue/white LED in dome design.

---

## 5. Reishi (Ganoderma lucidum)

Medicinal species. Slow-growing but visually dramatic. Produces either antler or conk forms depending on CO2 levels.

### Temperature

| Phase | Range | Optimum | Notes |
|---|---|---|---|
| Colonization | 75-86degF (24-30degC) | 80degF (27degC) | Warm colonization; slower at room temp |
| Fruiting | 68-80degF (20-27degC) | 72-75degF (22-24degC) | Moderate; fruits well at room temperature |

**Sources:** [Out-Grow](https://www.out-grow.com/blogs/growing-mushrooms/how-to-grow-reishi-mushrooms), [GroCycle](https://grocycle.com/grow-reishi-mushrooms/), [FreshCap](https://learn.freshcap.com/growing/candidates-for-cultivation-the-reishi-mushroom/)

### Humidity

| Phase | Range | Critical Minimum | Notes |
|---|---|---|---|
| Colonization | 85-95% RH | 80% | High humidity during spawn run |
| Fruiting | 80-90% RH | 75% | Conk form needs slightly less humidity than antler |

**Sources:** [Out-Grow](https://www.out-grow.com/blogs/growing-mushrooms/how-to-grow-reishi-mushrooms), [Fungi Academy](https://fungiacademy.com/how-to-grow-reishi-mushrooms/)
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

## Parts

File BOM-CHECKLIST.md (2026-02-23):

# The Void Core -- Bill of Materials Checklist

> Printable BOM checklist for the Void Core ESP32 prototype build.
> Check off each item as you source and receive it. All components must be on hand before starting the [Assembly Guide](ASSEMBLY-GUIDE.md).

> **Note:** This BOM is for the **prototype build** using the ESP32 DevKit V1.
> The production Void Core uses a Pi Zero W 2 -- see FIRMWARE-DOCS.md (Phase 20+) for the production BOM.

---

## 3D Printed Parts

Print all parts per [PRINT-SETTINGS.md](PRINT-SETTINGS.md). Material: PETG recommended, PLA acceptable for test prints only.

| | Part | Qty | Export Script | Notes |
|---|---|-----|---|---|
| [ ] | Base Housing | 1 | `cad/export/export_base.scad` | 203mm dia x 89mm H, ~200g PETG, ~12 hrs |
| [ ] | Dome -- Full **OR** Upper + Lower | 1 or 2 | `export_dome_full.scad` or `export_dome_upper.scad` + `export_dome_lower.scad` | Full requires 250mm+ build height; split fits 220mm beds |
| [ ] | Substrate Platform | 1 | `cad/export/export_platform.scad` | 140mm dia x 8mm H, ~30g PETG, ~1.5 hrs |
| [ ] | Vent Caps | 4 (printed as 1 set) | `cad/export/export_vent_cap.scad` | 16mm dia x 4mm H each, ~12g PETG total |

**Total filament:** ~380-440g PETG (one 1kg spool is sufficient with margin for test prints)

---

## Electronics -- Core

| | Component | Qty | Specification | Notes |
|---|---|-----|---|---|
| [ ] | ESP32 DevKit V1 | 1 | 38-pin, dual-core, Wi-Fi + BLE | Prototype controller. Must be 38-pin variant for correct GPIO layout |
| [ ] | BME280 breakout board | 1 | I2C, 3.3V, with on-board pull-ups | Temperature / humidity / pressure sensor. I2C address 0x76 or 0x77 |
| [ ] | Micro-USB cable | 1 | Data-capable (not charge-only) | Powers ESP32 separately from component 5V rail |

---

## Electronics -- LEDs

| | Component | Qty | Specification | Notes |
|---|---|-----|---|---|
| [ ] | UV-A LEDs 395nm | 6 | 5050 SMD, 20mA | Series string for grow/observation light |
| [ ] | Blue LEDs 450nm | 6 | 5050 SMD, 20mA | Series string for fruiting light |
| [ ] | UV-C LED 275nm | 1 | 3535 SMD | Germicidal sterilization. If Vf > 5V, add boost converter (see WIRING.md) |
| [ ] | PT4115 constant-current LED driver | 1 | 20mA per string | Drives UV-A + Blue LED strings from 5V rail |
| [ ] | Red 3mm indicator LED | 1 | Standard through-hole | UV-C active warning indicator, driven from GPIO 2 |

---

## Electronics -- Actuators

| | Component | Qty | Specification | Notes |
|---|---|-----|---|---|
| [ ] | 30mm 5V axial fan | 1 | 5V DC, 30mm | FAE (Fresh Air Exchange), PWM speed control via MOSFET on GPIO 14 |
| [ ] | Piezo humidifier disc | 1 | 20mm diameter, 113 kHz | Ultrasonic mist generation, sits in humidifier well (-X side of base) |

---

## Electronics -- Input / Safety

| | Component | Qty | Specification | Notes |
|---|---|-----|---|---|
| [ ] | Reed switch, normally-open | 1 | Glass body | Dome presence interlock -- wired IN SERIES with UV-C LED power path |
| [ ] | Neodymium magnet 6x2mm disc | 1 | 6mm diameter, 2mm thick | Press-fit into dome seating lip pocket (6.5mm pocket gives 0.5mm clearance) |
| [ ] | 12mm waterproof tactile button | 1 | With silicone cap | Mode cycling (short press) / UV-C trigger (3-second hold) |

---

## Electronics -- Power

| | Component | Qty | Specification | Notes |
|---|---|-----|---|---|
| [ ] | N-channel MOSFETs (IRLZ44N) | 5 | Logic-level, must saturate at 3.3V gate | Q1: UV-A, Q2: Blue, Q3: UV-C, Q4: Fan, Q5: Humidifier |
| [ ] | 220 ohm resistors | 6 | 1/4W | 5x MOSFET gate resistors (Q1-Q5) + 1x indicator LED current limiting |
| [ ] | CH224K USB-C PD sink IC | 1 | Negotiates 5V from USB-C PD source | Provides component 5V rail, separate from ESP32 USB power |
| [ ] | USB-C PD power adapter | 1 | 5V/3A minimum (15W) | Main power supply. Typical draw ~5.5W, peak ~10W |

---

## Hardware

| | Item | Qty | Notes |
|---|---|-----|---|
| [ ] | M2 screws + nuts | Assorted (8-12) | PCB mounting (ESP32 standoffs, BME280 mount) |
| [ ] | 22 AWG silicone wire | ~2m total | Red, black, and signal colors. Silicone jacket for flexibility in tight routing |
| [ ] | Heat shrink tubing | Assortment | For insulating solder joints, especially on MOSFET leads and LED connections |
| [ ] | Medium CA glue + accelerator | 1 set | Required if using split dome; optional for securing magnet in pocket |
| [ ] | Silicone gasket O-ring | 1 | 203mm ID, 2mm cross-section -- optional dome seal for humidity retention |

---

## Tools Required

| | Tool | Notes |
|---|---|---|
| [ ] | Soldering iron + solder | For all wire connections, MOSFET gate resistors, LED strings |
| [ ] | Wire strippers | 22 AWG compatible |
| [ ] | Multimeter | Continuity mode (reed switch test) + voltage mode (power rail verification) |
| [ ] | Small Phillips screwdriver | M2 hardware |
| [ ] | Flush cutters | Trimming component leads and wire ends |
| [ ] | Computer with PlatformIO | For compiling and flashing firmware to ESP32. See `firmware/platformio.ini` |

---

## Quick Reference: GPIO Pin Map

For wiring reference, see [firmware/WIRING.md](firmware/WIRING.md) for full circuit diagrams.

| GPIO | Function | Signal |
|---|---|---|
| 21 | BME280 SDA | I2C data |
| 22 | BME280 SCL | I2C clock |
| 25 | UV-A LEDs | MOSFET gate (Q1) |
| 26 | Blue LEDs | MOSFET gate (Q2) |
| 27 | UV-C LED | MOSFET gate (Q3), reed switch in series |
| 14 | Fan PWM | MOSFET gate (Q4), 25 kHz |
| 13 | Humidifier | MOSFET gate (Q5) |
| 16 | Reed switch | Input, internal pull-up, LOW = dome seated |
| 17 | Button | Input, internal pull-up, LOW = pressed |
| 2 | Red indicator LED | UV-C warning, active HIGH |

---

*Part of the Void Blueprints documentation.*
*See [ASSEMBLY-GUIDE.md](ASSEMBLY-GUIDE.md) for build instructions.*
*Generated from Phase 12 Plan 02 -- BOM Checklist*
*Last updated: 2026-02-22*

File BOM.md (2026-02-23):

# Bill of Materials -- The Void Grows Product Line

> Costed BOM for all three dome variants: The Void ($79 MSRP), Void Core ($299), Dark Dome ($49).
> All costs are planning estimates -- not purchase orders. Rounded to nearest $0.25 for components, $0.50 for assemblies.
> Pricing sourced from AliExpress (bulk), Digi-Key/Mouser (reference), LCSC (ICs), and manufacturer datasheets.
> Date: 2026-02-21

---

## 1. BOM: The Void (Base Dome) -- $79 MSRP / $59 Early Bird

### 1.1 Enclosure

| Component | Description | Qty | Unit Cost (1pc) | Unit Cost (1000pc) | Source / Supplier |
|---|---|---|---|---|---|
| Dome shell | Smoked polycarbonate, 8" dia x 6.5" tall, 2mm wall, truncated hemisphere | 1 | $8.00 | $3.00 | Injection mold (China contract manufacturer) |
| Base housing | Matte black ABS, 8" dia x 3.5" tall, textured finish | 1 | $6.00 | $2.50 | Injection mold (China contract manufacturer) |
| Silicone gasket ring | 190mm ID, 1.5mm cross-section, food-grade silicone | 1 | $0.75 | $0.25 | AliExpress / custom gasket supplier |
| Silicone rubber feet | 12mm dia x 3mm tall, adhesive-backed, set of 4 | 1 | $0.50 | $0.25 | AliExpress |
| **Enclosure subtotal** | | | **$15.25** | **$6.00** | |

### 1.2 Lighting

| Component | Description | Qty | Unit Cost (1pc) | Unit Cost (1000pc) | Source / Supplier |
|---|---|---|---|---|---|
| UV-A LEDs (395nm) | 5050 SMD, 60-80mW, 120-degree beam | 6 | $0.50 ea ($3.00) | $0.08 ea ($0.50) | AliExpress (100pc packs ~$8) |
| Blue LEDs (450nm) | 5050 SMD, 60-80mW, 120-degree beam | 6 | $0.25 ea ($1.50) | $0.05 ea ($0.25) | AliExpress / LCSC |
| UV-C LED (275nm) | 3535 SMD, 30-40mW radiant output, Seoul Viosys or equiv. | 1 | $4.00 | $2.50 | AliExpress ($3-4 ea in 10pc), Digi-Key reference |
| Red indicator LED | 3mm through-hole, standard red | 1 | $0.25 | $0.05 | AliExpress / LCSC |
| **Lighting subtotal** | | | **$8.75** | **$3.25** | |

### 1.3 Electronics

| Component | Description | Qty | Unit Cost (1pc) | Unit Cost (1000pc) | Source / Supplier |
|---|---|---|---|---|---|
| USB-C receptacle | 16-pin SMD, mid-mount | 1 | $0.50 | $0.15 | AliExpress / LCSC |
| USB-C PD sink IC | CH224K or IP2721, SOT-23 | 1 | $0.50 | $0.25 | LCSC |
| LED driver IC | PT4115 or equivalent, constant current | 1 | $0.50 | $0.15 | LCSC |
| 555 timer IC (x2) | NE555 / LMC555, SOP-8 package | 2 | $0.25 ea ($0.50) | $0.05 ea ($0.10) | LCSC ($0.02-0.10 ea bulk) |
| Reed switch | Normally-open, glass body, 5mm | 1 | $0.25 | $0.10 | AliExpress |
| Tactile push button | 12mm, waterproof silicone cap | 1 | $0.50 | $0.25 | AliExpress |
| PCB | 2-layer, 50mm x 30mm, FR-4 | 1 | $1.50 | $0.50 | JLCPCB / PCBWay |
| Passive components | Resistors (8x), capacitors (4x), TVS diode, PTC fuse, Zener | 1 set | $1.00 | $0.25 | LCSC |
| Neodymium magnet | 6mm x 2mm disc, N35 grade | 1 | $0.25 | $0.05 | AliExpress ($0.01 ea bulk) |
| **Electronics subtotal** | | | **$5.50** | **$1.75** | |

### 1.4 Mechanical / Airflow

| Component | Description | Qty | Unit Cost (1pc) | Unit Cost (1000pc) | Source / Supplier |
|---|---|---|---|---|---|
| Micropore tape filters | 3M Micropore, pre-cut strips for 12 vents | 1 set | $0.50 | $0.25 | 3M bulk / medical supply |
| Vent covers (dome) | Snap-in filter disc holders, molded into dome | 4 | Included in dome | Included in dome | Part of dome mold |
| Substrate platform | Perforated platform, molded into base | 1 | Included in base | Included in base | Part of base mold |
| USB-C cable | 1m USB-A to USB-C, black | 1 | $1.00 | $0.50 | AliExpress |
| **Mechanical subtotal** | | | **$1.50** | **$0.75** | |

### 1.5 Packaging

| Component | Description | Qty | Unit Cost (1pc) | Unit Cost (1000pc) | Source / Supplier |
|---|---|---|---|---|---|
| Outer box | Matte black rigid cardboard, UV-reactive ink, ~10x10x5" | 1 | $3.00 | $1.50 | Custom packaging supplier (Packlane, PakFactory) |
| Inner insert | Deep indigo tissue wrap / cardboard insert | 1 | $0.50 | $0.25 | Packaging supplier |
| Quick-start card | Matte black card stock, UV-reactive ink, 4x6" | 1 | $0.50 | $0.15 | Print shop |
| Micropore tape refill | Extra strip included for first grow cycle | 1 | $0.25 | $0.10 | 3M bulk |
| **Packaging subtotal** | | | **$4.25** | **$2.00** | |

### 1.6 Assembly & Labor

| Component | Description | Qty | Unit Cost (1pc) | Unit Cost (1000pc) | Source / Supplier |
|---|---|---|---|---|---|
| PCB assembly (SMT) | Solder paste, pick-and-place, reflow for ~20 components | 1 | $3.00 | $1.00 | JLCPCB assembly / contract manufacturer |
| Final assembly | Install PCB in base, attach gasket, apply micropore tape, quality check | 1 | $5.00 | $2.00 | Contract assembly (est. 10-15 min/unit at $8-12/hr) |
| Packaging labor | Box, insert dome, insert card, close and label | 1 | $1.00 | $0.50 | Contract assembly (est. 3-5 min/unit) |
| **Assembly subtotal** | | | **$9.00** | **$3.50** | |

### 1.7 The Void -- COGS Summary

| | 1 pc (prototype) | 100 pc (pilot) | 1000 pc (Kickstarter) | 5000 pc (scale) |
|---|---|---|---|---|
| Enclosure | $15.25 | $9.00 | $6.00 | $5.00 |
| Lighting | $8.75 | $5.00 | $3.25 | $3.00 |
| Electronics | $5.50 | $3.00 | $1.75 | $1.50 |
| Mechanical | $1.50 | $1.00 | $0.75 | $0.50 |
| Packaging | $4.25 | $2.75 | $2.00 | $1.75 |
| Assembly | $9.00 | $5.00 | $3.50 | $3.00 |
| **COGS Total** | **$44.25** | **$25.75** | **$17.25** | **$14.75** |

**Note:** 1pc prototype cost uses retail component prices. 100pc uses small-batch pricing. 1000pc assumes injection molding (tooling amortized separately -- see Section 4). 5000pc reflects optimized production.

---

## 2. BOM: Void Core (Smart Dome) -- $299 MSRP

The Void Core includes ALL base Void components plus the following additional components.

### 2.1 Additional Components (Beyond Base Void)

| Component | Description | Qty | Unit Cost (1pc) | Unit Cost (1000pc) | Source / Supplier |
|---|---|---|---|---|---|
| Raspberry Pi Zero W 2 | Quad-core ARM, Wi-Fi, BLE, 512MB RAM | 1 | $15.00 | $15.00 | Raspberry Pi Foundation (fixed MSRP) |
| BME280 sensor | Temp + humidity + pressure, I2C, breakout module | 1 | $3.00 | $1.50 | AliExpress ($2-3 ea module) |
| SCD40 CO2 sensor | Sensirion, I2C, 400-5000 ppm range (optional add-on) | 1 | $18.00 | $12.00 | Digi-Key ($18 ea), Mouser. NEEDS VALIDATION -- may be excluded to control costs |
| Piezo humidifier module | 20mm disc, 113 KHz, driver board included | 1 | $1.50 | $0.75 | AliExpress ($0.98-1.50 ea) |
| 30mm axial fan | 5V DC, PWM capable, <25 dB | 1 | $2.00 | $1.00 | AliExpress |
| Camera module | 5MP OV5647, CSI ribbon cable, Pi-compatible | 1 | $5.00 | $3.50 | AliExpress / Arducam ($5-8 ea) |
| WS2812B RGB LEDs | 5050 SMD, addressable, individual IC | 8 | $0.25 ea ($2.00) | $0.10 ea ($0.75) | AliExpress (100pc ~$10) |
| microSD card | 16GB, Class 10 | 1 | $3.00 | $2.50 | Bulk memory supplier |
| Upgraded PCB | 4-layer, 60mm x 40mm, additional headers for Pi / sensors | 1 | $3.00 | $1.00 | JLCPCB |
| Micro-USB to USB-C adapter | Internal power adapter for Pi Zero | 1 | $0.50 | $0.25 | AliExpress |
| Motorized damper (x2) | Micro servo SG51 or solenoid for vent control | 2 | $1.50 ea ($3.00) | $0.75 ea ($1.50) | AliExpress |
| Water reservoir | 100ml molded chamber, integrated in upgraded base | 1 | Included in base | Included in base | Part of Void Core base mold |
| Ribbon cables / connectors | CSI cable, I2C headers, wiring harness | 1 set | $2.00 | $0.75 | AliExpress |
| Upgraded base housing | Taller ABS base to accommodate Pi + reservoir (4.5" vs 3.5") | 1 | +$2.00 | +$1.00 | Separate mold or mold insert |
| Additional passive components | Voltage regulators, caps, connectors for Pi integration | 1 set | $1.50 | $0.50 | LCSC |
| **Void Core additional subtotal** | | | **$61.50** | **$42.00** | |

### 2.2 Void Core -- COGS Summary

| | 1 pc | 100 pc | 1000 pc | 5000 pc |
|---|---|---|---|---|
| Base Void COGS | $44.25 | $25.75 | $17.25 | $14.75 |
| Void Core additions | $61.50 | $48.00 | $42.00 | $38.00 |
| Upgraded packaging (larger box) | $1.00 | $0.75 | $0.50 | $0.50 |
| Additional assembly labor (20 min) | $4.00 | $3.00 | $2.50 | $2.00 |
| **Void Core COGS Total** | **$110.75** | **$77.50** | **$62.25** | **$55.25** |

**Note:** Pi Zero W 2 at $15 is a fixed price that does not decrease with volume (Raspberry Pi Foundation pricing). This makes it the single largest cost driver in the Void Core. The SCD40 CO2 sensor at $12-18 is the second largest. If both are included, electronics alone approach $30 at volume. Consider making SCD40 an optional upgrade to control COGS.

---

## 3. BOM: Dark Dome -- $49 MSRP

The Dark Dome is a stripped-down variant with NO electronics whatsoever.

### 3.1 Components

| Component | Description | Qty | Unit Cost (1pc) | Unit Cost (1000pc) | Source / Supplier |
|---|---|---|---|---|---|
| Dome shell | Smoked or clear polycarbonate, 8" dia x 6.5" tall (same mold as base Void) | 1 | $8.00 | $3.00 | Injection mold |
| Base housing | Matte black ABS, 8" dia x 3.5" tall (simplified -- no electronics bay needed, but same mold keeps cost down) | 1 | $6.00 | $2.50 | Injection mold (same mold as Void base) |
| Silicone gasket ring | 190mm ID, 1.5mm cross-section | 1 | $0.75 | $0.25 | AliExpress |
| Silicone rubber feet | 12mm x 3mm, set of 4 | 1 | $0.50 | $0.25 | AliExpress |
| Micropore tape filters | Pre-cut strips for 12 vents | 1 set | $0.50 | $0.25 | 3M bulk |
| Substrate platform | Same as base Void (molded into base) | 1 | Included | Included | Part of base mold |
| **Dark Dome parts subtotal** | | | **$15.75** | **$6.25** | |

### 3.2 Packaging (Simplified)

| Component | Description | Qty | Unit Cost (1pc) | Unit Cost (1000pc) | Source / Supplier |
|---|---|---|---|---|---|
| Outer box | Matte black cardboard, simpler print (no UV-reactive ink) | 1 | $2.00 | $1.00 | Packaging supplier |
| Quick-start card | Basic instructions, 4x6" | 1 | $0.25 | $0.10 | Print shop |
| **Packaging subtotal** | | | **$2.25** | **$1.10** | |

### 3.3 Assembly & Labor

| Component | Description | Qty | Unit Cost (1pc) | Unit Cost (1000pc) | Source / Supplier |
|---|---|---|---|---|---|
| Final assembly | Attach gasket, apply micropore tape, quality check | 1 | $2.00 | $0.75 | Contract assembly (est. 5 min/unit) |
| Packaging labor | Box, insert dome, insert card | 1 | $0.50 | $0.25 | Contract assembly (est. 2 min/unit) |
| **Assembly subtotal** | | | **$2.50** | **$1.00** | |

### 3.4 Dark Dome -- COGS Summary

| | 1 pc | 100 pc | 1000 pc | 5000 pc |
|---|---|---|---|---|
| Parts | $15.75 | $9.00 | $6.25 | $5.25 |
| Packaging | $2.25 | $1.50 | $1.10 | $1.00 |
| Assembly | $2.50 | $1.50 | $1.00 | $0.75 |
| **Dark Dome COGS Total** | **$20.50** | **$12.00** | **$8.25** | **$7.00** |

---

## 4. Cost Analysis Summary

### 4.1 Tooling Costs (One-Time, Amortized)

These are upfront fixed costs required before production begins. They are NOT included in per-unit COGS above but must be recovered through unit sales.

| Tooling Item | Estimated Cost | Notes |
|---|---|---|
| Dome shell injection mold | $8,000 - $12,000 | Single-cavity P20 steel mold. Polycarbonate requires hardened steel. Shared across Void + Dark Dome. |
| Base housing injection mold (Void / Dark Dome) | $6,000 - $10,000 | Single-cavity, ABS. Less complex than dome (no optical clarity needed). |
| Base housing injection mold (Void Core) | $8,000 - $12,000 | Separate mold for taller base with reservoir chamber. Only needed at 350+ Kickstarter backers. |
| PCB design & prototyping | $500 - $1,000 | One-time engineering cost. |
| Packaging design & plates | $500 - $1,000 | One-time creative / print setup. |
| **Total tooling (Void + Dark Dome)** | **$15,000 - $24,000** | Minimum to start Kickstarter fulfillment |
| **Total tooling (all variants)** | **$23,000 - $36,000** | Including Void Core base mold |

**Tooling amortization at 1000 units:**

Using midpoint estimates ($19,500 for Void + Dark Dome tooling):

| Variant | Tooling Share | Amortized Per Unit (1000 total units) |
|---|---|---|
| The Void | ~60% of dome + base mold | $11.70 |
| Dark Dome | ~20% of dome + base mold (shares molds) | $3.90 |
| Void Core | ~20% of shared + own base mold | $7.80 + $10.00 = $17.80 |

### 4.2 Per-Unit COGS at Scale (Including Amortized Tooling)

| | 1000 units COGS | + Tooling (amortized) | Total Landed Cost |
|---|---|---|---|
| **The Void** | $17.25 | $11.70 | **$28.95** |
| **Void Core** | $62.25 | $17.80 | **$80.05** |
| **Dark Dome** | $8.25 | $3.90 | **$12.15** |

### 4.3 Margin Analysis

| Metric | The Void | Void Core | Dark Dome |
|---|---|---|---|
| **MSRP** | $79.00 | $299.00 | $49.00 |
| **COGS (1000pc, no tooling)** | $17.25 | $62.25 | $8.25 |
| **Gross Margin (MSRP)** | **$61.75 (78%)** | **$236.75 (79%)** | **$40.75 (83%)** |
| **COGS (with amortized tooling)** | $28.95 | $80.05 | $12.15 |
| **Gross Margin (with tooling)** | **$50.05 (63%)** | **$218.95 (73%)** | **$36.85 (75%)** |
| **Brand Bible target** | 40-50% | 40-50% | 40-50% |
| **Status** | EXCEEDS target | EXCEEDS target | EXCEEDS target |

**All three variants exceed the 40-50% margin target at MSRP, even after tooling amortization.**

### 4.4 Kickstarter Economics

Kickstarter takes ~5% platform fee + ~3-5% payment processing. Using 8% combined.

| Metric | The Void ($59 EB) | Void Core ($249 KS tier) | Dark Dome (stretch goal) |
|---|---|---|---|
| **Kickstarter price** | $59.00 | $249.00 | $39.00 (est.) |
| **After KS fees (8%)** | $54.28 | $229.08 | $35.88 |
| **COGS (1000pc + tooling)** | $28.95 | $80.05 | $12.15 |
| **Net margin** | **$25.33 (43%)** | **$149.03 (60%)** | **$23.73 (48%)** |
| **Shipping estimate** | $8.00 (domestic) | $10.00 (domestic) | $7.00 (domestic) |
| **Net after shipping** | **$17.33 (29%)** | **$139.03 (56%)** | **$16.73 (34%)** |

**Kickstarter viability assessment:**

- **The Void at $59 early bird:** Viable. After all fees and shipping, ~29% net margin. Not huge, but positive. Volume improvements at 2000+ units would push COGS down further. The $59 price point works as a customer acquisition tool -- recurring Void Pack revenue is the real margin driver.
- **Void Core at $249:** Very comfortable. 56% net margin even after fees and shipping. The Pi Zero at $15 is the cost floor but still leaves excellent margin.
- **Dark Dome at ~$39 (stretch goal estimate):** Viable. 34% net margin after fees and shipping. The near-zero electronics cost is the key advantage. Could potentially go as low as $35 and still be marginally positive.

### 4.5 Breakeven Analysis

| Variant | Fixed Tooling Cost | Net Margin Per Unit (KS price after fees + shipping) | Units to Break Even on Tooling |
|---|---|---|---|
| The Void | $17,000 (share of molds) | $17.33 | ~981 units |
| Void Core | $20,000 (share + own mold) | $139.03 | ~144 units |
| Dark Dome | $5,500 (share of molds) | $16.73 | ~329 units |

**The Void needs ~1000 backers to break even on tooling alone. This should be the Kickstarter funding goal calculation basis.** Void Core breaks even very quickly due to high per-unit margin. Dark Dome is a stretch goal and needs ~330 units.

### 4.6 Component Cost Risk Analysis

Components representing >20% of COGS are flagged as supply chain risks.

| Component | % of Void COGS (1000pc) | % of Void Core COGS | Risk Level | Notes |
|---|---|---|---|---|
| **Dome shell (injection)** | 17.4% of $17.25 | -- | Moderate | Single-source (mold owner). Mitigated by having mold design files. |
| **Base housing (injection)** | 14.5% of $17.25 | -- | Moderate | Same as dome -- single mold source. |
| **Raspberry Pi Zero W 2** | -- | 24.1% of $62.25 | **HIGH** | Fixed $15 MSRP. Supply shortages in 2021-2023 showed Pi availability can be unreliable. NEEDS VALIDATION: Consider ESP32-S3 ($3-5) as fallback. |
| **SCD40 CO2 sensor** | -- | 19.3% of $62.25 | **HIGH** | $12-18 per unit. Single-source (Sensirion). Consider making optional or using cheaper MH-Z19B ($5-8) alternative. NEEDS VALIDATION. |
| **UV-C LED (275nm)** | 14.5% of $17.25 | -- | Moderate | Specialty component but multiple AliExpress/Seoul Viosys sources. Price has decreased in recent years. |
| **Assembly labor** | 20.3% of $17.25 | -- | Low | Scalable with contract manufacturing. Can be reduced with jig design and automation. |

---

## 5. Sourcing Notes

### 5.1 Preferred Suppliers

| Category | Primary Source | Secondary Source | Notes |
|---|---|---|---|
| **Passive ICs (555, drivers, PD sink)** | LCSC Electronics | Digi-Key (reference/validation) | LCSC has best pricing for Chinese-manufactured equivalents. Order with PCBs from JLCPCB for combined shipping. |
| **LEDs (UV-A, Blue, RGB)** | AliExpress (100pc+ packs) | LCSC for SMD reels | 395nm and 450nm 5050 LEDs are commodity parts. Multiple redundant sources. |
| **UV-C LED (275nm)** | AliExpress (Seoul Viosys compatible) | LED Supply (ledsupply.com) for branded Seoul Viosys | UV-C LEDs are specialty but increasingly available. Verify radiant power with datasheets. |
| **PCBs + Assembly** | JLCPCB (PCB + SMT assembly) | PCBWay | JLCPCB offers combined PCB fabrication + component sourcing + SMT assembly. Best value for <5000 units. |
| **Injection molding** | China contract manufacturer (Alibaba RFQ) | US domestic (Protolabs, Xometry) for prototyping | China offers 50-70% cost savings on tooling and per-unit. US domestic for speed on prototypes. |
| **Raspberry Pi Zero W 2** | Raspberry Pi Foundation authorized distributors | Pimoroni, Adafruit, SparkFun | Fixed $15 pricing. Verify stock availability before committing. Lead time can be 8-16 weeks when constrained. |
| **Sensors (BME280)** | AliExpress modules | Digi-Key (Bosch genuine) | AliExpress modules are $2-3 ea. Genuine Bosch chips are $2-4 on Digi-Key. Module includes breakout board. |
| **Packaging** | PakFactory / Packlane | Local print shop for prototypes | UV-reactive ink adds ~$0.25-0.50/unit over standard printing. Get samples before committing. |

### 5.2 Lead Times

| Component | Typical Lead Time | Notes |
|---|---|---|
| Injection mold tooling | 4-8 weeks (China), 2-4 weeks (US) | Must begin immediately after design freeze |
| Injection molded parts | 2-3 weeks after tooling | Per production run |
| PCBs + assembly | 1-2 weeks (JLCPCB standard) | 3-5 day express available |
| UV-C LEDs | 1-3 weeks (AliExpress) | Stock dependent |
| Raspberry Pi Zero W 2 | 2-16 weeks | Highly variable. Order early. |
| Custom packaging | 3-5 weeks | After design approval |
| **Total supply chain (first batch)** | **8-14 weeks** | Critical path is injection mold tooling |

### 5.3 Minimum Order Quantities

| Component | MOQ | Cost Impact |
|---|---|---|
| Injection molding (per run) | 500-1000 units typical | Below 500, per-unit cost increases significantly |
| PCBs (JLCPCB) | 5 units | No practical constraint |
| PCB assembly (JLCPCB SMT) | 2 units | No practical constraint |
| LEDs (AliExpress) | 10-100 units per pack | No practical constraint |
| UV-C LEDs | 2-10 per pack (retail), 100+ (bulk) | Order in bulk packs of 100+ for best pricing |
| Custom packaging | 100-500 units | Most packaging suppliers have 100-250 unit MOQ |
| Raspberry Pi Zero W 2 | 1 unit (retail), negotiable at volume | Retail channel has 5-unit limits per order at some retailers |

### 5.4 Cost Reduction Opportunities

| Opportunity | Potential Savings | Feasibility | Notes |
|---|---|---|---|
| Replace ATtiny85 + 555 timers with single ATtiny85 | $0.10-0.25/unit | High | ATtiny85 can replace both 555 timers in firmware. Reduces component count. |
| ESP32-S3 instead of Pi Zero W 2 (Void Core) | $10-12/unit | Medium | ESP32-S3 is $3-5 vs $15 for Pi Zero. Trades Linux ecosystem for cost savings. Requires firmware rewrite. NEEDS VALIDATION. |
| MH-Z19B instead of SCD40 (Void Core CO2) | $5-8/unit | Medium | MH-Z19B is $5-8 vs $12-18 for SCD40. Larger physical package but adequate accuracy. |
| Multi-cavity injection mold | $1-2/unit at 5000+ | Medium | Doubles tooling cost but halves cycle time and per-unit cost. Worth it at 5000+ units. |
| Eliminate UV-reactive packaging ink | $0.25-0.50/unit | Low priority | UV-reactive ink is a brand-defining feature. Only cut if margins are critically tight. |
| Shared mold for Dark Dome (no separate base mold) | $6,000-10,000 tooling savings | High | Use same base mold as The Void. Dark Dome base just has empty electronics bay. Minor material waste but huge tooling savings. |

---

## 6. COGS Comparison Table (All Variants at Scale)

| Component Category | The Void (1000pc) | Void Core (1000pc) | Dark Dome (1000pc) |
|---|---|---|---|
| Enclosure | $6.00 | $7.00 | $6.25 |
| Lighting (LEDs) | $3.25 | $4.00 | $0.00 |
| Electronics (ICs, PCB, passives) | $1.75 | $33.50 | $0.00 |
| Mechanical (filters, vents, cable) | $0.75 | $1.75 | $0.25 |
| Packaging | $2.00 | $2.50 | $1.10 |
| Assembly labor | $3.50 | $6.00 | $1.00 |
| **COGS (no tooling)** | **$17.25** | **$54.75** | **$8.60** |
| Tooling amortized (1000 units) | $11.70 | $17.80 | $3.90 |
| **Total landed cost** | **$28.95** | **$72.55** | **$12.50** |
| **MSRP** | **$79.00** | **$299.00** | **$49.00** |
| **Gross margin %** | **63%** | **76%** | **74%** |

**Note on Void Core variance:** The Void Core electronics subtotal ($33.50) includes the Pi Zero W 2 ($15.00) and SCD40 ($12.00) which together account for $27 of the $33.50. If SCD40 is made optional, Void Core electronics drop to ~$21.50 and total COGS to ~$48.75, improving margin further.

---

*BOM version: 1.0 -- Planning estimates for Phase 2 product design specification.*
*All costs subject to validation with actual supplier quotes during prototyping.*
*Last updated: 2026-02-21*

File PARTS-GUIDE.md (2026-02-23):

# The Void -- Parts Sourcing Guide

> Complete component sourcing guide for community builders.
> This document lists every component needed to build The Void, with specifications, quantities, costs, and recommended suppliers.
> For assembly instructions, see BUILD-GUIDE.md. For electronics behavior, see FIRMWARE-DOCS.md.

---

## 1. Overview

### What This Guide Covers

This is the definitive shopping list for building a Void dome. Every component is listed with exact specifications, estimated costs, and where to buy it. If it goes into the dome, it is in this guide.

### Three Build Tiers

| Tier | What You Build | Electronics? | Estimated Total Cost |
|---|---|---|---|
| **Dark Dome** | Passive cultivation chamber, no electronics | None | ~$12 |
| **The Void** (base) | Full dome with UV-A, Blue, and UV-C LEDs, mode button, USB-C power | Base electronics | ~$42-57 |
| **Void Core** (advanced) | Smart dome with Pi Zero, sensors, fan, humidifier, camera, app control | Full smart electronics | ~$120-160 |

Costs are estimates based on single-unit purchases from recommended suppliers. Buying in bulk (5+ units) reduces per-unit cost significantly.

### How to Use This Guide

1. Decide which variant you are building (Dark Dome, base Void, or Void Core)
2. Print the 3D parts (Section 2)
3. Order the components for your tier (Sections 3-4)
4. Gather tools (Section 5)
5. Follow BUILD-GUIDE.md for assembly

---

## 2. Printed Parts (From Void Blueprints)

All 3D-printable parts are included in the Void Blueprints package. See BUILD-GUIDE.md for STL files, print settings, and detailed instructions.

| Part | File | Qty | Filament (g) | Est. Cost |
|---|---|---|---|---|
| Dome shell | `void-dome-full.stl` | 1 | ~150g | $4.50 |
| Base housing | `void-base.stl` | 1 | ~200g | $6.00 |
| Substrate platform | `void-platform.stl` | 1 | ~30g | $0.90 |
| Vent caps | `void-vent-cap.stl` | 4 | ~12g (3g each) | $0.36 |
| **Total filament** | | | **~392g** | **~$11.76** |

**Recommended filament:** PETG (smoked/dark tint for dome, black for base). ~$30/kg spool. One spool is sufficient for the complete build with material to spare.

**Smaller printers (<210mm bed):** Use split dome files (`void-dome-split-upper.stl` + `void-dome-split-lower.stl`) instead of `void-dome-full.stl`. Bond halves with CA glue.

---

## 3. Electronics -- Base Void

These components are needed for the base Void (full build). The Dark Dome does not need any of these.

### 3.1 Enclosure Components (Non-Printed)

| Component | Specification | Qty | Est. Cost | Recommended Source | Search Terms / Notes |
|---|---|---|---|---|---|
| Silicone gasket ring | 190mm ID, 1.5mm cross-section, food-grade silicone | 1 | $0.75 | AliExpress | "190mm silicone O-ring 1.5mm" -- buy a 5-pack for spares |
| Silicone rubber feet | 12mm diameter x 3mm tall, adhesive-backed, clear or black | 4 (1 set) | $0.50 | AliExpress / Amazon | "12mm silicone bumper feet adhesive" -- sold in sheets of 20-50 |
| Neodymium magnet | 6mm diameter x 2mm thick, N35 grade, disc | 1 | $0.25 | AliExpress | "6x2mm neodymium magnet" -- buy a 10-pack ($2-3 for 10) |

**Subtotal (enclosure):** ~$1.50

### 3.2 Lighting Components

| Component | Specification | Qty | Est. Cost | Recommended Source | Search Terms / Notes |
|---|---|---|---|---|---|
| UV-A LEDs (395nm) | 5050 SMD, 60-80mW, 120-degree beam, 3.0-3.4V forward | 6 | $3.00 ($0.50 ea) | AliExpress | "5050 UV LED 395nm SMD" -- buy a 100-pack (~$8) for best value; you need 6 |
| Blue LEDs (450nm) | 5050 SMD, 60-80mW, 120-degree beam, 3.0V forward | 6 | $1.50 ($0.25 ea) | AliExpress / LCSC | "5050 blue LED 450nm SMD" -- extremely common part |
| UV-C LED (275nm) | 3535 SMD, 30-40mW radiant output, 120-degree beam | 1 | $4.00 | Digi-Key / Mouser | "275nm UV-C LED 3535" -- use Digi-Key/Mouser for genuine parts (counterfeit risk on AliExpress for UV-C). Seoul Viosys or equivalent. AliExpress ($3-4 ea in 10-packs) is acceptable if you verify with a UV meter. |
| Red indicator LED | 3mm through-hole, standard red, 2.0V forward | 1 | $0.25 | AliExpress / LCSC | "3mm red LED through hole" -- commodity part, any brand |

**Subtotal (lighting):** ~$8.75

**Alternative UV-C LED sources:** If Digi-Key/Mouser pricing is too high for a single unit, AliExpress sellers offer Seoul Viosys-compatible 275nm LEDs in 10-packs for $30-40. Buy extras -- UV-C LEDs are fragile and expensive to replace individually.

### 3.3 Electronics Components

| Component | Specification | Qty | Est. Cost | Recommended Source | Search Terms / Notes |
|---|---|---|---|---|---|
| USB-C receptacle | 16-pin SMD, mid-mount, through-hole legs for stability | 1 | $0.50 | AliExpress / LCSC | "USB-C female connector 16pin SMD" -- very common; verify pinout matches your PCB design |
| USB-C PD sink IC | CH224K, SOT-23-6 package (or IP2721 as alternative) | 1 | $0.50 | LCSC | "CH224K" on LCSC -- $0.15-0.30 each. Configures USB-C for 5V output. Datasheet available from WCH (Nanjing Qinheng). |
| LED driver IC | PT4115, SOT-89 package, constant current | 1 | $0.50 | LCSC | "PT4115" on LCSC -- $0.10-0.20 each. Drives both LED strings at constant 20mA. Alternative: XLSEMI XL4015. |
| 555 timer IC (x2) | NE555 or LMC555 (CMOS preferred for lower power), SOP-8 package | 2 | $0.50 ($0.25 ea) | LCSC | "LMC555 SOP-8" on LCSC -- $0.05-0.10 each. CMOS variant draws less current than bipolar NE555. |
| Reed switch | Normally-open, glass body, ~14mm long, activation distance 5mm | 1 | $0.25 | AliExpress | "glass reed switch normally open" -- buy a 10-pack (~$2). Test each one with a magnet before installing. |
| Tactile push button | 12mm diameter, waterproof with silicone cap, momentary | 1 | $0.50 | AliExpress | "12mm waterproof tactile switch silicone cap" -- ensure it is momentary (not latching) |
| PCB | 2-layer FR-4, 50mm x 30mm | 1 | $1.50 | JLCPCB / PCBWay | Upload Gerber files (when available). JLCPCB: $2 for 5 boards (minimum order). PCBWay similar pricing. |
| Passive components set | 8x resistors (assorted values for LED current limiting and timer configuration), 4x capacitors (100uF electrolytic, 0.1uF ceramic, 1000uF electrolytic for 12h timer, 100uF for UV-C timer), 1x TVS diode (ESD protection), 1x PTC fuse (500mA resettable), 1x Zener diode (5.5V clamp) | 1 set | $1.00 | LCSC | Order with PCB from JLCPCB for combined shipping. Buy assortment kits from AliExpress if ordering separately ("resistor capacitor assortment kit SMD 0805"). |

**Subtotal (electronics):** ~$5.50

**Optional: ATtiny85 microcontroller**

| Component | Specification | Qty | Est. Cost | Recommended Source | Search Terms / Notes |
|---|---|---|---|---|---|
| ATtiny85 | ATTINY85-20PU (DIP-8) or ATTINY85-20SU (SOP-8) | 1 | $0.75 | LCSC / Digi-Key | "ATtiny85" -- DIP-8 for breadboard prototyping, SOP-8 for PCB. Replaces both 555 timers and adds mode memory. See FIRMWARE-DOCS.md Section 3. |
| 8-pin DIP socket | (if using DIP-8 ATtiny85) | 1 | $0.10 | AliExpress | "8 pin DIP IC socket" -- allows removing the ATtiny85 for reprogramming |

### 3.4 Mechanical / Airflow Components

| Component | Specification | Qty | Est. Cost | Recommended Source | Search Terms / Notes |
|---|---|---|---|---|---|
| Micropore tape | 3M Micropore surgical tape, 1" (25mm) width | 1 roll | $0.50 | Amazon / pharmacy | "3M Micropore tape 1 inch" -- one roll provides enough tape for dozens of vent filter replacements. Also available at any pharmacy/drugstore. |
| USB-C cable | 1m (3ft), USB-A to USB-C, black, data+power | 1 | $1.00 | AliExpress / Amazon | "USB A to USB C cable 1m black" -- any standard cable works. Avoid charge-only cables (need power pins). |

**Subtotal (mechanical):** ~$1.50

### 3.5 Base Void -- Complete Bill of Materials

| Category | Subtotal |
|---|---|
| Printed parts (filament) | ~$11.76 |
| Enclosure components | ~$1.50 |
| Lighting | ~$8.75 |
| Electronics | ~$5.50 |
| Mechanical / airflow | ~$1.50 |
| **Total (base Void)** | **~$29.01** |

**Note:** Prices assume single-unit purchases from AliExpress with economy shipping (2-4 weeks). Using Digi-Key/Mouser for all components (faster US shipping) increases electronics cost by approximately $10-15 but guarantees genuine parts and 3-5 day delivery.

**With tools and consumables** (solder, glue, etc.), budget ~$42-57 total for a first build.

---

## 4. Electronics -- Void Core Additions

The Void Core includes ALL base Void components (Section 3) plus the following. Only build these if you are creating a Void Core.

| Component | Specification | Qty | Est. Cost | Recommended Source | Search Terms / Notes |
|---|---|---|---|---|---|
| Raspberry Pi Zero W 2 | Quad-core ARM Cortex-A53, Wi-Fi, BLE, 512MB RAM, CSI camera port | 1 | $15.00 | Raspberry Pi authorized distributors (Pimoroni, Adafruit, SparkFun) | "Raspberry Pi Zero W 2" -- fixed $15 MSRP. Check stock before ordering; supply can be constrained. 8-16 week lead time during shortages. |
| BME280 sensor module | Temperature + humidity + barometric pressure, I2C, breakout board with headers | 1 | $3.00 | AliExpress | "BME280 module I2C" -- $2-3 each. Module includes level shifting and pull-ups. Verify it is BME280 (not BMP280, which lacks humidity). |
| SCD40 CO2 sensor | Sensirion SCD40, I2C, 400-5000 ppm range, photoacoustic | 1 | $18.00 | Digi-Key / Mouser | "SCD40 Sensirion" -- $18 at Digi-Key. This is the most expensive sensor. **Optional** -- can be omitted to reduce cost. Alternative: MH-Z19B NDIR sensor ($5-8 on AliExpress, larger package but adequate accuracy). |
| Piezo humidifier module | 20mm disc, 113 KHz, with driver board | 1 | $1.50 | AliExpress | "20mm ultrasonic mist maker module" or "piezo humidifier disc 113KHz" -- $0.98-1.50 each. Ensure driver board is included. |
| 30mm axial fan | 5V DC, 30x30x10mm, PWM capable (4-pin preferred), <25 dB | 1 | $2.00 | AliExpress | "30mm fan 5V DC" -- if 4-pin PWM is unavailable, a 2-pin 5V fan can be speed-controlled via MOSFET from Pi GPIO. |
| Camera module | 5MP OV5647 or 8MP IMX219, CSI ribbon cable, Pi Zero compatible | 1 | $5.00 | AliExpress / Arducam | "Pi Zero camera module OV5647" -- $5-8 each. Verify ribbon cable is the narrow type for Pi Zero (not full-size Pi). Arducam modules are reliable. |
| WS2812B RGB LEDs | 5050 SMD, addressable (individual IC per LED), single data pin | 8 | $2.00 ($0.25 ea) | AliExpress | "WS2812B 5050 SMD LED" -- buy a strip or 100-pack. You need 8 individual LEDs or a small ring module. Alternative: buy a WS2812B 8-LED ring module ($2-3) pre-assembled. |
| microSD card | 16GB minimum, Class 10 / U1 or better | 1 | $3.00 | Amazon | "16GB microSD Class 10" -- SanDisk or Samsung recommended for reliability. 32GB provides more timelapse storage. |
| Upgraded PCB | 4-layer FR-4, 60mm x 40mm, additional headers for Pi and sensor connections | 1 | $3.00 | JLCPCB | Upload Gerber files (when available). 4-layer adds ~$1 over 2-layer for cleaner routing. |
| Micro-USB to USB-C adapter | Internal adapter for powering the Pi Zero from the Void's USB-C input | 1 | $0.50 | AliExpress | "micro USB to USB-C adapter" -- small inline adapter. Alternative: solder power wires directly to Pi Zero test pads. |
| Micro servo motors (x2) | SG51 or equivalent, 5V, micro size, for motorized vent dampers | 2 | $3.00 ($1.50 ea) | AliExpress | "SG51 micro servo" or "micro servo 5V" -- small enough to fit in the base housing. Alternative: small solenoid valves. |
| Ribbon cables / connectors | CSI ribbon cable (Pi Zero width), I2C Qwiic/Stemma headers, 4-pin JST connectors | 1 set | $2.00 | AliExpress | "Pi Zero camera cable" + "JST 4pin connector set" -- buy assortment packs. |
| Additional passive components | 3.3V voltage regulator (for sensors from 5V rail), additional capacitors, connectors | 1 set | $1.50 | LCSC | Order with JLCPCB PCB for combined shipping. |

### Void Core Additions Subtotal

| Category | Subtotal |
|---|---|
| Pi Zero W 2 | $15.00 |
| Sensors (BME280 + SCD40) | $21.00 |
| Active climate (humidifier + fan + dampers) | $6.50 |
| Camera + storage | $8.00 |
| RGB LEDs (WS2812B x8) | $2.00 |
| PCB + connectors + passives | $7.00 |
| **Void Core additions total** | **~$59.50** |

### Void Core -- Complete Build Cost

| Category | Cost |
|---|---|
| Base Void complete | ~$29.01 |
| Void Core additions | ~$59.50 |
| **Void Core total** | **~$88.51** |

**With tools, consumables, and shipping**, budget ~$120-160 total for a first Void Core build.

**Cost reduction option:** Omit the SCD40 CO2 sensor (-$18) if you do not need precise CO2 monitoring. The fan can be controlled on a simple timer schedule instead. This brings the Void Core additions down to ~$41.50.

---

## 5. Tools Required

### Essential Tools (All Builds)

These tools are needed for any variant (Dark Dome, base Void, or Void Core).

| Tool | Est. Cost | Notes |
|---|---|---|
| 3D printer (220x220mm+ bed) | $150-300 (Ender 3 class) | You likely already have this if you are building from Void Blueprints |
| PETG filament (~400g) | ~$12 | See Section 2 for filament details |
| Flush cutters | $5-10 | For trimming support material and component leads |
| CA (super) glue | $3-5 | For securing the magnet in the dome rim |
| Scissors | -- | For cutting micropore tape |

### Electronics Tools (Base Void and Void Core)

| Tool | Est. Cost | Recommended | Notes |
|---|---|---|---|
| Soldering iron | $25-70 | Pinecil ($25) or TS80P ($70) | Temperature-controlled iron is essential. Pinecil is the best value for beginners. Avoid cheap unregulated irons. |
| Solder | $8-15 | 60/40 tin-lead (0.8mm diameter) or lead-free SAC305 | 60/40 is easier to work with. Lead-free is required in some regions (EU RoHS). |
| Multimeter | $15-30 | Any basic digital multimeter | For testing connections, verifying LED polarity, and checking the reed switch. Essential for troubleshooting. |
| Wire strippers | $5-10 | -- | For preparing wire connections |
| Helping hands / PCB holder | $10-20 | -- | Holds the PCB while soldering. A third-hand tool or PCB vise makes SMD soldering much easier. |
| Heat shrink tubing | $5-8 | Assortment pack (various diameters) | For insulating wire connections and protecting solder joints. Use a lighter or heat gun to shrink. |
| Small Phillips screwdriver | $3-5 | -- | For PCB mounting screws (M3) |
| Isopropyl alcohol (IPA) | $3-5 | 90%+ concentration | For cleaning flux residue after soldering and cleaning the build plate |
| Solder wick or desoldering pump | $3-5 | -- | For fixing solder mistakes. Buy both if new to soldering. |

### Void Core Additional Tools

| Tool | Est. Cost | Notes |
|---|---|---|
| microSD card reader | $5-10 | For flashing Raspberry Pi OS to the microSD card |
| Computer with internet | -- | For downloading Pi OS image and flashing |
| USB micro-B cable | $3-5 | For initial Pi Zero setup (if not using SSH over WiFi) |

### Optional Tools (Post-Processing)

| Tool | Est. Cost | Notes |
|---|---|---|
| Sandpaper (200-1200 grit) | $5-10 | For dome surface smoothing. Progressive wet sanding. |
| Clear coat spray | $8-12 | Krylon UV-resistant clear gloss for improved dome transparency |
| Matte black spray paint | $5-8 | For base exterior finish if desired |
| Smoke tint spray | $8-12 | VHT Nite-Shades for tinting clear PETG domes |

---

## 6. Sourcing Tips

### Supplier Guide

| Supplier | Best For | Shipping (to US) | Pricing | Notes |
|---|---|---|---|---|
| **AliExpress** | LEDs, connectors, passives, gaskets, magnets, fans, modules | 2-4 weeks (economy), 7-15 days (standard) | Cheapest for small quantities | Buy 10-20% extra for defects. Quality varies by seller -- check reviews and order ratings. |
| **LCSC Electronics** | ICs (555 timers, CH224K, PT4115, ATtiny85), SMD passives | Combined with JLCPCB order | Best IC pricing | LCSC is the component sourcing arm of JLCPCB. Order ICs when you order PCBs for combined shipping. |
| **JLCPCB** | PCB fabrication, PCB assembly (SMT) | 5-10 days (standard), 3-5 days (express) | $2-5 for 5 boards | Upload Gerber files, choose specs, order. Can also handle SMT assembly -- they solder components onto your boards. |
| **PCBWay** | PCB fabrication (alternative to JLCPCB) | Similar to JLCPCB | Comparable | Good alternative if JLCPCB is backordered or you want a second quote. |
| **Digi-Key** | UV-C LED (genuine parts), sensors (SCD40), precision components | 3-5 days (US domestic) | Higher than AliExpress | Guaranteed genuine parts. Use for UV-C LED (counterfeit risk on AliExpress) and Sensirion sensors. |
| **Mouser** | Same as Digi-Key (alternative) | 3-5 days (US domestic) | Comparable to Digi-Key | Good alternative to Digi-Key. Same parts catalogs. |
| **Amazon** | Tools, filament, micropore tape, microSD cards, cables | 1-2 days (Prime) | Moderate | Best for tools and consumables. Filament selection is good. |
| **Raspberry Pi authorized distributors** | Pi Zero W 2 | Varies (Pimoroni: 5-10 days UK, Adafruit: 3-5 days US) | Fixed $15 MSRP | Check stock on rpilocator.com before ordering. Multiple authorized resellers. |

### Ordering Strategy

**Single build (1 unit):**
1. Order PCBs from JLCPCB + ICs from LCSC in one shipment
2. Order LEDs, connectors, magnets, gaskets, and modules from AliExpress (allow 2-4 weeks)
3. Order UV-C LED from Digi-Key (domestic shipping, genuine part)
4. Order tools, filament, tape, and cables from Amazon
5. Order Pi Zero W 2 from authorized distributor (Void Core only)

**Multiple builds (5+ units):**
- Buy LED packs in 100-count: UV-A ($8/100), Blue ($5/100)
- Buy reed switches, magnets, and gaskets in 10-20 packs
- Order PCBs in batches of 10 (only slightly more than 5)
- Consider JLCPCB SMT assembly service -- they solder components for you ($10-20 setup + $0.50-1.00 per board)

### Key Warnings

- **UV-C LEDs:** Counterfeit risk on AliExpress. Some sellers label 365nm (UV-A) LEDs as 275nm (UV-C). Genuine UV-C LEDs are invisible to the human eye (275nm is deep UV, not visible purple). If a "UV-C" LED glows visibly purple, it is likely UV-A. Use Digi-Key/Mouser for guaranteed genuine Seoul Viosys or equivalent UV-C parts.
- **BME280 vs BMP280:** Many AliExpress sellers label BMP280 modules as BME280. The BMP280 does NOT measure humidity -- it only measures temperature and pressure. Verify the chip marking says "BME280" (not "BMP280") when the module arrives.
- **Pi Zero W 2 supply:** Raspberry Pi stock fluctuates. During shortages, lead times can stretch to 8-16 weeks. Check availability before committing to a Void Core build. ESP32-S3 is a potential fallback platform ($3-5) but requires different firmware.
- **Component tolerances:** Electrolytic capacitors (used in 555 timer circuits) have +/-20% tolerance. This means your 12-hour timer may actually run 10-14 hours. This is normal for hardware timing. Use the ATtiny85 option for precise timing.

---

## 7. Cost Summary

### Per-Variant Cost Breakdown

#### Dark Dome (~$12)

| Category | Cost |
|---|---|
| Filament (PETG, ~392g) | $11.76 |
| Silicone gasket | $0.75 |
| Rubber feet | $0.50 |
| Micropore tape | $0.50 |
| **Total** | **~$13.51** |

No electronics, no magnet, no cable needed.

#### The Void -- Base Build (~$42-57)

| Category | 1-Unit Cost | 5-Unit Cost (per unit) |
|---|---|---|
| Filament (PETG, ~392g) | $11.76 | $11.76 |
| Enclosure (gasket, feet, magnet) | $1.50 | $1.00 |
| Lighting (LEDs) | $8.75 | $5.00 |
| Electronics (ICs, PCB, passives) | $5.50 | $3.00 |
| Mechanical (tape, cable) | $1.50 | $1.00 |
| **Parts subtotal** | **~$29.01** | **~$21.76** |
| Tools and consumables (first build) | ~$13-28 | -- |
| **Total (first build)** | **~$42-57** | **~$22/unit** |

#### Void Core (~$120-160)

| Category | 1-Unit Cost | 5-Unit Cost (per unit) |
|---|---|---|
| Base Void parts | $29.01 | $21.76 |
| Void Core additions | $59.50 | $48.00 |
| **Parts subtotal** | **~$88.51** | **~$69.76** |
| Tools and consumables (first build) | ~$31-71 | -- |
| **Total (first build)** | **~$120-160** | **~$70/unit** |
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

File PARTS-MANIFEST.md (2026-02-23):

# The Void -- Parts Manifest

All printable parts for The Void mushroom cultivation dome. Each part has a dedicated export script in `cad/export/` that renders at $fn=128 for high-quality STL output.

## Export Workflow

1. Open the export script in OpenSCAD
2. Render (F6)
3. Export as STL (F7)
4. Save with the output filename listed below

## Parts Table
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

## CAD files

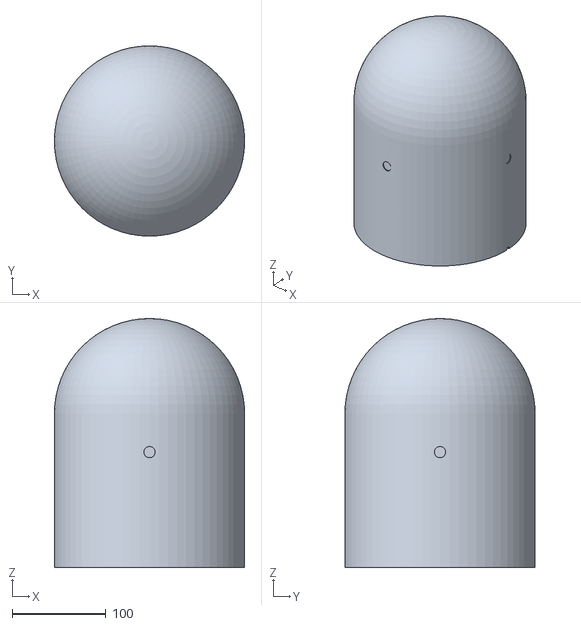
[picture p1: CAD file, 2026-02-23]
cad/export/stl/void-dome-full.stl
203.0 x 203.0 x 265.6

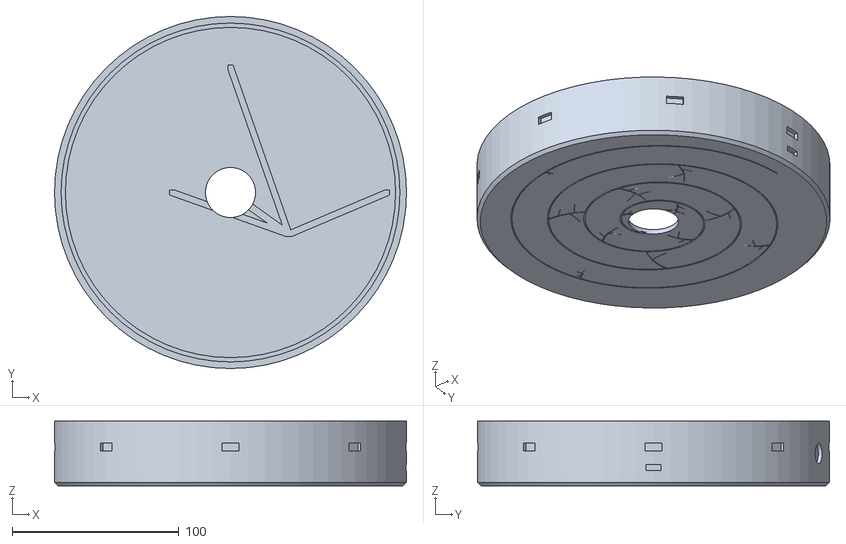
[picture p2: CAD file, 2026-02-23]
cad/export/stl/void-base.stl
211.1 x 211.1 x 38.8

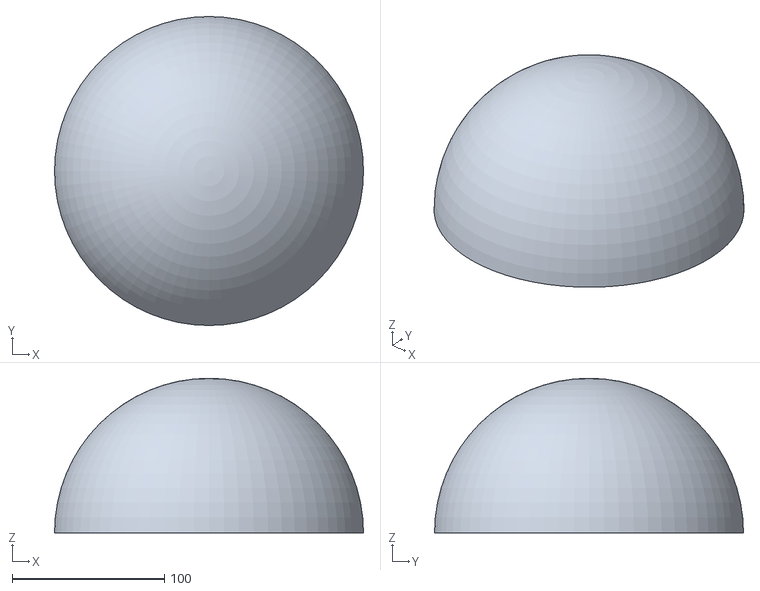
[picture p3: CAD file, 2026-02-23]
cad/export/stl/void-dome-upper.stl
203.0 x 203.0 x 101.5

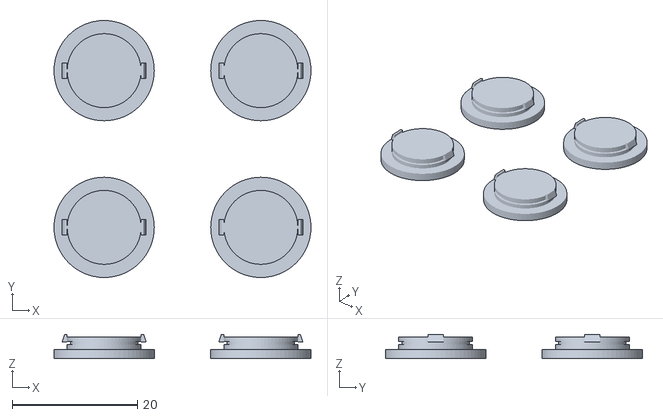
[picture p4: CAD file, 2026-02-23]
cad/export/stl/void-vent-cap.stl
41.0 x 41.0 x 3.90

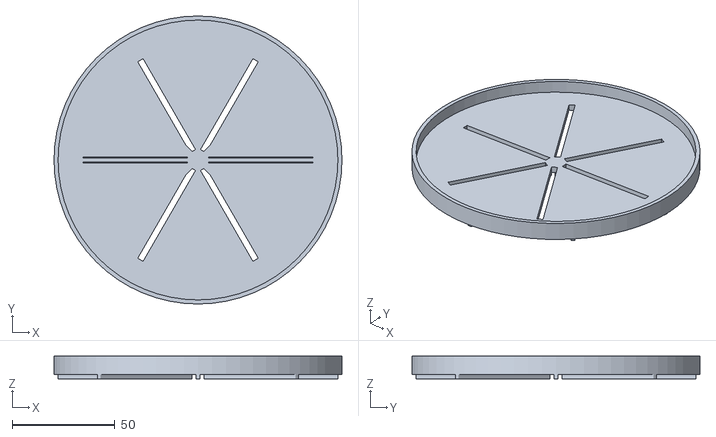
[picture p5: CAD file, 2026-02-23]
cad/export/stl/void-platform.stl
140.0 x 140.0 x 11.0

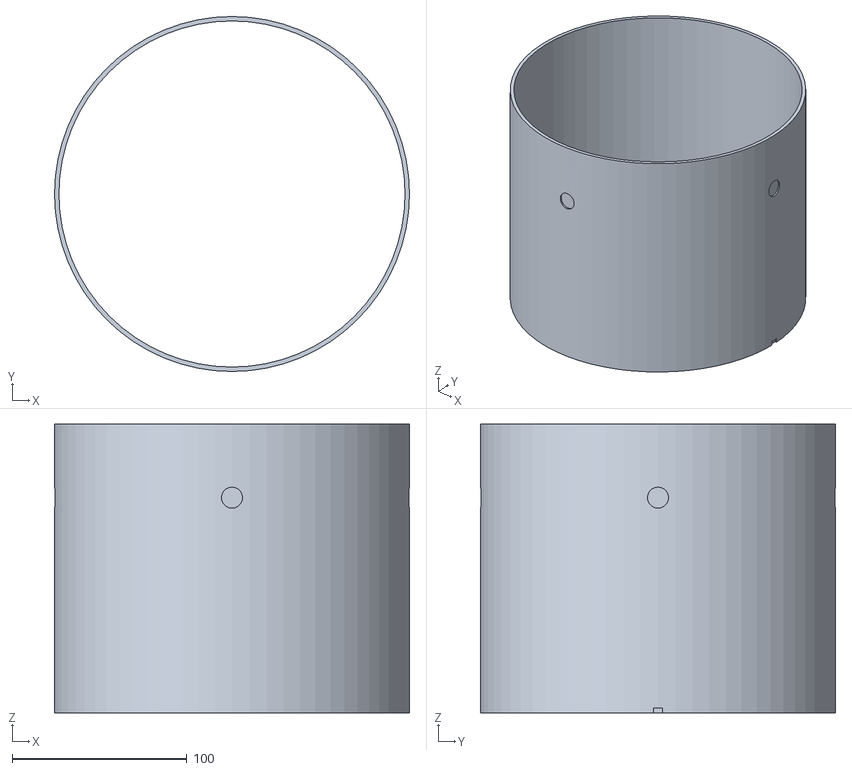
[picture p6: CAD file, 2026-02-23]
cad/export/stl/void-dome-lower.stl
203.0 x 203.0 x 165.1

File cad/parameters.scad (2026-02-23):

// =============================================================================
// The Void — Parametric Constants (Golden Ratio Cloche)
// =============================================================================
// Every proportion derived from φ = 1.618 and the 8" dome diameter.
// The same ratio found in nautilus shells, sunflower spirals,
// and the mycelium branching patterns this dome nurtures.
//
// Design lineage: D → R → arch → straight (×φ) → base (÷φ²)
// =============================================================================

// === GLOBAL ===
quality = "preview";  // "preview" or "render"
$fn = (quality == "render") ? 128 : 64;

phi = 1.6180339887;          // Golden ratio
golden_angle = 137.507764;   // 360° / φ²
fdm_tolerance = 0.2;         // mm — FDM print tolerance
epsilon = 0.01;              // mm — CSG overlap

// === OVERALL DIMENSIONS ===
D = 203;                     // 8" dome outer diameter (product spec, fixed)
R = D / 2;                   // 101.5mm
wall = 2.5;                  // mm — shell thickness

// === DOME SHELL ===
// Derivation chain: R → arch_height → straight_height (×φ) → dome_height
arch_height = R;                              // 101.5mm — semicircular cap
straight_height = arch_height * phi;          // 164.2mm — φ × arch
dome_height = straight_height + arch_height;  // 265.7mm — total dome

// === BASE HOUSING ===
// Derivation chain: R → base_h (÷φ²), wall → base_overhang (×φ)
base_h = R / (phi * phi);      // 38.8mm — R/φ²
base_overhang = wall * phi;     // 4.0mm — wall×φ
base_floor = 3;                 // mm — floor thickness
base_chamfer = 2;               // mm — bottom edge chamfer
r_outer = R + base_overhang;    // 105.5mm — total base radius

// === PLATFORM ===
platform_diameter = 140;        // mm — growing platform
platform_rim_height = 6;        // mm — rim around edge
platform_z = base_floor + 2;    // mm — clearance above base floor

// === VOID CORE COMPONENTS ===
// Port from Phase 10 — internal electronics layout unchanged by dome shape

// Raspberry Pi Zero W 2
pi_zero_width  = 30;   // mm
pi_zero_length = 65;   // mm

// 30mm axial fan
fan_diameter = 30;      // mm
fan_depth    = 10;      // mm

// BME280 sensor breakout
bme280_width  = 13;    // mm
bme280_length = 11;    // mm

// Humidifier reservoir
humidifier_reservoir_diameter = 40;  // mm
humidifier_reservoir_depth    = 25;  // mm

// Servo
servo_width  = 12;     // mm
servo_length = 23;     // mm

// Cable channel
cable_channel_depth = 2;  // mm — preserves floor integrity

// === VENT SYSTEM ===
vent_hole_diameter = 12;      // mm — exhaust vent holes
vent_cap_flange = 16;         // mm — cap outer flange
vent_cap_insert = 11.8;       // mm — 12 - 2×fdm_tolerance
vent_cap_snap_protrusion = 1; // mm

// === EASTER EGG ENGRAVING ===
etch_depth = 0.8;       // mm
line_width = 1.2;        // mm
max_radius = R - 8;      // mm — pattern boundary

// =============================================================================
// PROPORTION SUMMARY
// =============================================================================
// Dome diameter:     203.0mm (8.0")
// Straight walls:    164.2mm (φ × arch)
// Arch cap:          101.5mm (R)
// Total dome:        265.7mm (10.5")
// Base height:        38.8mm (R/φ²)
// Base overhang:       4.0mm (wall×φ)
// Total height:      304.5mm (12.0")
//
// Golden ratios embedded:
//   straight / arch  = φ     (1.618)
//   base / arch      = 1/φ²  (0.382)
//   overhang / wall  = φ     (1.618)
// =============================================================================

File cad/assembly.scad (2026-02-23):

// =============================================================================
// The Void — Full Assembly Visualization (Golden Ratio Cloche)
// =============================================================================
// VISUALIZATION ONLY — do not export as STL. Use cad/export/ for individual parts.
//
// Color-coded assembly showing all components in correct relative positions.
// Toggle between full dome and split dome views.
//
// Color scheme:
//   DimGray        — Base housing
//   Gray           — Substrate platform
//   DarkSlateGray  — Dome (70% opacity)
//   LightSlateGray — Vent caps
//
// Public API:  void_assembly(split = false)
// =============================================================================

include <parameters.scad>
use <dome.scad>
use <dome_split.scad>
use <base.scad>
use <platform.scad>
use <vent_cap.scad>

// === VENT CAP PLACEMENT ===
// Positions 4 vent caps at the exhaust vent hole locations on the dome wall.
// Vent holes are at 75% of straight_height, at 90-deg intervals (matching dome.scad).
// Caps oriented flange outward, insert facing inward through wall.
module _place_vent_caps() {
    vent_z = straight_height * 0.75;

    for (angle = [0, 90, 180, 270]) {
        rotate([0, 0, angle])
            translate([R, 0, vent_z])
                rotate([0, 90, 0])      // Rotate cap to face radially outward
                    vent_cap();
    }
}

// === PUBLIC: Full cloche assembly ===
// Renders all components in correct positions with color coding.
// split=true shows dome_lower() + dome_upper() instead of void_dome().
module void_assembly(split = false) {
    // Base at origin
    color("DimGray")
        void_base();

    // Platform inside base (elevated above floor)
    color("Gray")
        translate([0, 0, platform_z])
            substrate_platform();

    // Dome on top of base
    if (split) {
        color("DarkSlateGray", 0.7)
            translate([0, 0, base_h]) {
                dome_lower();
                dome_upper();
            }
    } else {
        color("DarkSlateGray", 0.7)
            translate([0, 0, base_h])
                void_dome();
    }

    // Vent caps on dome wall
    color("LightSlateGray")
        translate([0, 0, base_h])
            _place_vent_caps();
}

// === Standalone preview ===
// Full assembly (default)
void_assembly();

// Uncomment for split dome view:
// void_assembly(split = true);

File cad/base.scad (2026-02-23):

// =============================================================================
// The Void — Base Housing Module (Golden Ratio Cloche)
// =============================================================================
// Slim 38.8mm (R/phi^2) base housing all Void Core electronics.
// Adapted from Phase 10's 89mm base to fit golden-ratio-derived height.
//
// Component layout: water (-X) separated from electronics (+X)
// to prevent moisture damage.
//
// Public API:  void_base()
// Helpers:     base_shell(), base_interior(), component_mounts(),
//              wall_cutouts(), cable_channels(), dome_seating()
// Easter egg:  _golden_spiral(), _curved_branch(), _mycelium_branches(),
//              _phi_symbol(), _easter_egg_pattern()
// =============================================================================

include <parameters.scad>

// === LOCAL CONSTANTS ===
// Internal clearance: base_h - base_floor = ~35.8mm
_inner_r = R - wall;                      // 99mm — interior radius
_internal_clearance = base_h - base_floor; // ~35.8mm available height

// Component positions (same XY layout as Phase 10, adapted Z)
// Water (-X), electronics (+X)
_pi_x = 35;
_pi_y = -25;
_fan_x = 0;
_fan_y = 0;
_sensor_x = 0;
_sensor_y = 75;
_humidifier_x = -35;
_humidifier_y = 0;
_servo_x = -70;
_servo_y = 40;

// Standoff dimensions
_standoff_od = 5;          // mm — outer diameter
_pi_hole_d = 2.5;         // M2.5
_fan_hole_d = 3;           // M3
_servo_hole_d = 2;         // M2

// === BASE SHELL ===
// Outer form from cloche_preview: cylinder + bottom chamfer ring
module base_shell() {
    // Main cylinder (above chamfer)
    translate([0, 0, base_chamfer])
        cylinder(h = base_h - base_chamfer, r = r_outer);
    // Bottom chamfer ring
    cylinder(h = base_chamfer, r1 = r_outer - base_chamfer, r2 = r_outer);
}

// === BASE INTERIOR ===
// Hollow cavity starting at floor height
module base_interior() {
    translate([0, 0, base_floor])
        cylinder(h = base_h + epsilon, r = _inner_r);
}

// === DOME SEATING ===
// Annular groove at top of base for dome bottom edge to sit in.
// Depth: 2mm into top wall, width: wall + 0.2mm tolerance
module dome_seating() {
    seat_depth = 2;
    seat_width = wall + fdm_tolerance;
    // Groove at top of base wall
    translate([0, 0, base_h - seat_depth])
        difference() {
            cylinder(h = seat_depth + epsilon, r = R + fdm_tolerance/2);
            cylinder(h = seat_depth + epsilon, r = R - seat_width + fdm_tolerance/2);
        }
}

// === COMPONENT MOUNTS ===
// All internal additive features: standoffs, walls, shelves
module component_mounts() {
    // --- Pi Zero W 2 mount (+X side) ---
    // 4 standoffs at 23x58mm pattern, M2.5 holes, 5mm height from floor
    _pi_standoffs();

    // --- Fan mount (center) ---
    // 4 standoffs at 24mm spacing, M3, 3mm height
    _fan_standoffs();

    // --- BME280 sensor shelf (+X, near wall) ---
    // 10mm elevated shelf with retention lip
    _sensor_shelf();

    // --- Humidifier well (-X side) ---
    // 40mm diameter raised wall, 22mm deep
    _humidifier_well();

    // --- Servo mount (-Y side) ---
    // 2 posts at 28mm spacing, M2 holes, 5mm height
    _servo_standoffs();
}

// --- Pi Zero standoffs ---
// 23mm x 58mm hole pattern (Pi Zero W 2 mounting holes)
module _pi_standoffs() {
    standoff_h = 5;
    dx = 23 / 2;
    dy = 58 / 2;
    for (ox = [-dx, dx], oy = [-dy, dy]) {
        translate([_pi_x + ox, _pi_y + oy, base_floor])
            difference() {
                cylinder(h = standoff_h, r = _standoff_od / 2);
                translate([0, 0, -epsilon])
                    cylinder(h = standoff_h + 2 * epsilon, r = _pi_hole_d / 2);
            }
    }
}

// --- Fan mount standoffs ---
// 24mm square spacing around center, M3 holes, 3mm height
module _fan_standoffs() {
    standoff_h = 3;
    offset = 24 / 2;
    for (ox = [-offset, offset], oy = [-offset, offset]) {
        translate([_fan_x + ox, _fan_y + oy, base_floor])
            difference() {
                cylinder(h = standoff_h, r = _standoff_od / 2);
                translate([0, 0, -epsilon])
                    cylinder(h = standoff_h + 2 * epsilon, r = _fan_hole_d / 2);
            }
    }
}

// --- BME280 sensor shelf ---
// L-bracket shelf elevated 10mm (reduced from Phase 10's 20mm)
// with retention lip to hold breakout board
module _sensor_shelf() {
    shelf_z = 10;                  // Elevation from floor (was 20mm)
    shelf_w = bme280_width + 0.4;  // Width + tolerance
    shelf_l = bme280_length + 0.4; // Length + tolerance
    shelf_t = 1.5;                 // Shelf thickness
    lip_h = 1;                     // Retention lip height

    translate([_sensor_x - shelf_w / 2, _sensor_y - shelf_l / 2, base_floor]) {
        // Support column
        cube([shelf_w, shelf_l, shelf_z]);
        // Shelf platform
        translate([0, 0, shelf_z])
            cube([shelf_w, shelf_l, shelf_t]);
        // Retention lip on two edges
        translate([0, 0, shelf_z + shelf_t])
            cube([shelf_w, 1, lip_h]);
        translate([0, shelf_l - 1, shelf_z + shelf_t])
            cube([shelf_w, 1, lip_h]);
    }
}

// --- Humidifier well ---
// Raised cylindrical wall (not floor depression — floor too thin)
// 40mm diameter, 22mm deep (adapted from 25mm for 38.8mm base)
// with weep hole at bottom for overflow
module _humidifier_well() {
    well_d = humidifier_reservoir_diameter;
    well_wall = 2;                 // Well wall thickness
    well_h = 22;                   // Depth (was 25mm in Phase 10)
    well_od = well_d + 2 * well_wall;

    translate([_humidifier_x, _humidifier_y, base_floor])
        difference() {
            // Outer wall
            cylinder(h = well_h, r = well_od / 2);
            // Inner cavity
            translate([0, 0, -epsilon])
                cylinder(h = well_h + 2 * epsilon, r = well_d / 2);
        }
}

// --- Servo mount standoffs ---
// 2 posts at 28mm spacing, M2 holes, 5mm height
module _servo_standoffs() {
    standoff_h = 5;
    spacing = 28 / 2;
    for (oy = [-spacing, spacing]) {
        translate([_servo_x, _servo_y + oy, base_floor])
            difference() {
                cylinder(h = standoff_h, r = _standoff_od / 2);
                translate([0, 0, -epsilon])
                    cylinder(h = standoff_h + 2 * epsilon, r = _servo_hole_d / 2);
            }
    }
}

// === WALL CUTOUTS ===
// All subtractive wall features: USB-C, button, LED, intake vents
module wall_cutouts() {
    // USB-C cutout (+X side, centered at z=8mm from floor)
    _usbc_cutout();

    // Button hole (+Y side, centered at z=base_h/2)
    _button_cutout();

    // LED indicator hole (+Y side, offset from button)
    _led_cutout();

    // 8 intake vent slots (evenly spaced around perimeter)
    _intake_vents();
}

// --- USB-C cutout ---
// 9mm x 3.5mm rectangular opening on +X wall
module _usbc_cutout() {
    usbc_w = 9;
    usbc_h = 3.5;
    usbc_z = base_floor + 8;  // Center at 8mm above floor

    rotate([0, 0, 0])  // +X axis (0 degrees)
        translate([r_outer - wall - epsilon, -usbc_w / 2, usbc_z - usbc_h / 2])
            cube([wall + 2 * epsilon, usbc_w, usbc_h]);
}

// --- Button hole ---
// 12mm diameter hole on +Y wall, centered vertically
module _button_cutout() {
    button_d = 12;
    button_z = base_h / 2;

    rotate([0, 0, 70])  // +Y side, offset from USB-C
        translate([r_outer - wall / 2, 0, button_z])
            rotate([0, 90, 0])
                cylinder(h = wall + 2 * epsilon, r = button_d / 2, center = true);
}

// --- LED indicator hole ---
// 3mm diameter hole on +Y wall, offset from button
module _led_cutout() {
    led_d = 3;
    led_z = base_h / 2;

    rotate([0, 0, 90])  // Offset from button
        translate([r_outer - wall / 2, 0, led_z])
            rotate([0, 90, 0])
                cylinder(h = wall + 2 * epsilon, r = led_d / 2, center = true);
}

// --- 8 intake vent slots ---
// Evenly spaced around perimeter, 10mm wide x 5mm tall
// Centered at z = base_h * 0.6 (~23mm)
module _intake_vents() {
    vent_w = 10;
    vent_h = 5;
    vent_z = base_h * 0.6;

    for (angle = [0 : 45 : 315]) {
        rotate([0, 0, angle])
            translate([r_outer - wall - epsilon, -vent_w / 2, vent_z - vent_h / 2])
                cube([wall + 2 * epsilon, vent_w, vent_h]);
    }
}

// === CABLE CHANNELS ===
// 4 hull-based floor routing channels (2mm deep in 3mm floor)
// Connecting USB-C area to Pi, Pi to fan, Pi to sensor, Pi to humidifier
module cable_channels() {
    ch_w = 3;      // Channel width
    ch_d = cable_channel_depth;  // 2mm deep (from parameters.scad)

    // Channel 1: USB-C area (+X wall) to Pi Zero
    _cable_channel(
        _inner_r - 5, 0,       // Near +X wall
        _pi_x, _pi_y,          // Pi Zero position
        ch_w, ch_d
    );
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

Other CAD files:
cad/cloche_preview.scad
cad/dome.scad
cad/dome_split.scad
cad/export/export_base.scad
cad/export/export_dome_full.scad
cad/export/export_dome_lower.scad
cad/export/export_dome_upper.scad
cad/export/export_platform.scad
cad/export/export_vent_cap.scad
cad/golden_easter_egg.scad
cad/platform.scad
cad/vent_cap.scad

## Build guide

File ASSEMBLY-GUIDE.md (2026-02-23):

# The Void Core -- Assembly Guide

> Step-by-step assembly instructions for the Void Core ESP32 prototype.
> Total build time: approximately 90-120 minutes (excluding print time).

**Before you start:** Verify all components are on hand using [BOM-CHECKLIST.md](BOM-CHECKLIST.md). Print all parts per [PRINT-SETTINGS.md](PRINT-SETTINGS.md). Flash firmware to the ESP32 using PlatformIO before assembly (see `firmware/platformio.ini`).

**Tools needed:** Soldering iron + solder, wire strippers, multimeter, small Phillips screwdriver, flush cutters.

---

## Phase A: Pre-Assembly Inspection (~5 min)

Inspect all printed parts before committing to wiring and gluing. Catching fit issues now saves hours of rework.

### Steps

1. **Lay out all printed parts.** You should have: base housing (203mm dia x 89mm tall), dome (full or upper + lower halves), substrate platform (140mm dia), and 4 vent caps (16mm dia each). Check for warping -- the base must sit flat on a table with no rocking.

2. **Test-fit vent caps into dome exhaust holes.** Each cap (16mm outer diameter) should friction-fit into the 12mm exhaust vent holes with slight resistance from the snap-fit tabs. If too tight, sand the inner diameter lightly with 220-grit sandpaper. If too loose, reprint vent caps at 0.1mm less tolerance (reduce `fdm_tolerance` in `cad/parameters.scad` from 0.2mm to 0.1mm).

3. **If using split dome:** Dry-fit the upper and lower halves together. The 1mm alignment step ring on the inner wall should register cleanly with less than 0.5mm visible gap. Do NOT glue yet -- that happens in Phase E.

4. **Verify platform seats correctly.** Place the substrate platform (140mm dia) inside the base housing. It should rest flat on the platform support ledge at z=45mm on the 3mm-wide support ring (r=67-70mm). The 8 drainage ribs (1mm tall, 1.5mm wide, at 45-degree intervals) should face up.

5. **Check connector cutouts on base housing.** Inspect the USB-C cutout (9mm x 3.5mm), button hole (12mm diameter), and LED indicator hole (3mm diameter) on the base wall. All should be clean openings with no stringing or bridging residue. Clean with flush cutters if needed.

### Go / No-Go Checkpoint A

- [ ] Base sits flat, no warping
- [ ] Vent caps friction-fit into dome exhaust holes
- [ ] Split dome halves register cleanly (if applicable)
- [ ] Platform sits flat on support ledge inside base
- [ ] Connector cutouts are clean

**Proceed to Phase B only if all checks pass.**

---

## Phase B: Magnet & Reed Switch Installation (~10 min)

Install the dome magnet and base reed switch that form the UV-C hardware safety interlock. This interlock physically prevents UV-C radiation when the dome is removed.

### Steps

1. **Press-fit the 6x2mm neodymium magnet into the dome seating lip pocket.** The pocket is 6.5mm diameter x 2.5mm deep (from `parameters.scad`: `magnet_pocket_diameter=6.5`, `magnet_pocket_depth=2.5`), giving 0.5mm clearance around the 6mm magnet. The magnet should sit flush with or slightly below the lip surface. If the fit is loose, secure with a small drop of CA glue. The magnet pocket is located at 0 degrees on the dome seating lip.

2. **Mount the reed switch inside the base housing wall.** Position the glass-body reed switch on the interior of the base wall, aligned with the magnet position (0 degrees on the base rim, directly below where the dome magnet sits when seated). Solder two 150mm wire tails (use signal-colored wire for easy identification) to the reed switch leads. Use heat shrink tubing on the solder joints to prevent shorts.

3. **VERIFY -- UV-C SAFETY INTERLOCK TEST (mandatory):**
   - Place the dome on the base with the alignment notch (5mm wide x 3mm deep) registered correctly.
   - Set your multimeter to continuity mode.
   - Touch the probes to the two reed switch wire tails.
   - **Dome seated:** Multimeter should beep (circuit closed -- magnet closes reed switch).
   - **Dome lifted:** Multimeter should show open circuit (no beep -- magnet too far from reed switch).
   - This is the UV-C safety interlock. **DO NOT proceed to Phase C if this test fails.** Check magnet polarity/orientation, reed switch alignment, and magnet-to-switch distance (should be less than 10mm when dome is seated).

### Go / No-Go Checkpoint B

- [ ] Magnet seated flush in dome lip pocket
- [ ] Reed switch mounted and aligned with magnet position
- [ ] **Continuity test PASSES: closed when dome seated, open when dome lifted**

**Proceed to Phase C only if the interlock test passes.**

---

## Phase C: Electronics Wiring (~45-60 min)

Wire all electronic components following [firmware/WIRING.md](firmware/WIRING.md) exactly. Wire in the order below -- power connections come last to prevent accidental shorts during assembly.

### Steps

**1. I2C Bus -- BME280 Sensor**

Wire the BME280 breakout board to the ESP32:
- BME280 VIN --> ESP32 3V3
- BME280 GND --> ESP32 GND
- BME280 SDA --> ESP32 GPIO 21
- BME280 SCL --> ESP32 GPIO 22

The breakout board has on-board pull-up resistors for I2C -- no external pull-ups needed.

**2. LED MOSFETs -- UV-A, Blue, UV-C**

Wire 3 N-channel MOSFETs (IRLZ44N) for the LED strings. Each MOSFET follows the same pattern:

| MOSFET | GPIO | Gate Resistor | Drain Connection | Source |
|---|---|---|---|---|
| Q1 (UV-A) | GPIO 25 | 220 ohm | UV-A LED string cathode (via PT4115 driver from 5V) | GND |
| Q2 (Blue) | GPIO 26 | 220 ohm | Blue LED string cathode (via PT4115 driver from 5V) | GND |
| Q3 (UV-C) | GPIO 27 | 220 ohm | Reed switch terminal B (see step 3) | GND |

For each MOSFET:
- Solder a 220 ohm resistor between the ESP32 GPIO pin and the MOSFET gate.
- Connect MOSFET source to the GND bus.
- Connect MOSFET drain to the LED string cathode (Q1, Q2) or reed switch (Q3).

The PT4115 constant-current LED driver sits between the 5V rail and the UV-A/Blue LED string anodes, providing regulated 20mA per string.

**3. UV-C Series Interlock**

This is the critical safety circuit. The reed switch is wired IN SERIES in the UV-C LED power path so that UV-C physically cannot operate without the dome seated:

```
[5V rail] --> [UV-C LED + current limiting] --> [Reed switch terminal A]
[Reed switch terminal B] --> [Q3 MOSFET drain] --> [Q3 source] --> [GND]
```

**Important:** If your UV-C LED has Vf > 5V (most 275nm LEDs are 5.5-6.5V), replace the current-limiting resistor with a 5V-to-9V boost converter module (MT3608 or similar). See WIRING.md for details.

The interlock works even if firmware crashes -- it is a physical circuit break, not a software check.

**3b. Reed Switch -- Software Monitoring (GPIO 16)**

In addition to the hardware interlock above, the firmware monitors dome presence via GPIO 16 for logging and dashboard status. Connect ESP32 GPIO 16 to reed switch terminal A (the same terminal connected to the UV-C LED cathode). The ESP32's internal pull-up on GPIO 16 reads LOW when the reed switch is closed (dome seated) and HIGH when open (dome removed). See WIRING.md "Reed Switch (Dome Presence)" section for the full circuit.

**4. Fan**

Wire the 30mm 5V fan through MOSFET Q4:
- Fan+ (red wire) --> 5V rail
- Fan- (black wire) --> Q4 MOSFET drain
- Q4 source --> GND
- ESP32 GPIO 14 --> 220 ohm --> Q4 gate

GPIO 14 provides hardware PWM at 25 kHz, 8-bit resolution (duty cycle 0-255) for fan speed control.

**5. Humidifier**

Wire the piezo humidifier disc through MOSFET Q5:
- Humidifier+ (red wire) --> 5V rail
- Humidifier- (black wire) --> Q5 MOSFET drain
- Q5 source --> GND
- ESP32 GPIO 13 --> 220 ohm --> Q5 gate

Same topology as the fan circuit, but driven with on/off duty cycling (not PWM).

**6. Button**

Wire the 12mm waterproof tactile button between GPIO 17 and GND:
- Button terminal A --> ESP32 GPIO 17
- Button terminal B --> GND

The ESP32 uses its internal pull-up resistor on GPIO 17 -- no external resistor needed. The button reads LOW when pressed.

**7. Indicator LED**

Wire the red 3mm indicator LED with a current-limiting resistor:
- ESP32 GPIO 2 --> 220 ohm resistor --> Red LED anode
- Red LED cathode --> GND

This LED lights during UV-C sterilization as a visual warning. GPIO 2 is the built-in LED on most ESP32 DevKits.

**8. Power**

- **Component 5V rail:** The CH224K USB-C PD sink IC negotiates 5V from the USB-C PD power adapter. This 5V rail powers all external components (LEDs, fan, humidifier, UV-C). Requires a USB-C PD adapter rated for at least 5V/3A (15W). Typical draw is ~5.5W, peak ~10W.
- **ESP32 power:** The ESP32 DevKit V1 is powered separately through its own micro-USB port. The DevKit's onboard regulator provides 3.3V to GPIO pins.
- **Common ground:** All GND connections (ESP32 GND, 5V rail GND, all MOSFET sources, sensor GND) MUST share a common ground bus. Connect the ESP32 GND pin to the 5V rail GND.

**9. Pre-Power Verification (mandatory before connecting ESP32):**

Use a multimeter to check:
- [ ] No short between 5V rail and GND bus (should read open / high resistance)
- [ ] No short between any GPIO pin and GND or VCC
- [ ] Each MOSFET gate resistor reads approximately 220 ohm
- [ ] Reed switch wires are not shorted to adjacent pins
- [ ] All solder joints are clean with no bridging

### Go / No-Go Checkpoint C

- [ ] All 10 GPIO connections wired per WIRING.md pin table (including GPIO 16 to reed switch)
- [ ] 5 MOSFETs installed with gate resistors
- [ ] UV-C series interlock wired (reed switch in series with UV-C LED)
- [ ] No shorts detected on multimeter check
- [ ] All solder joints heat-shrunk or insulated

**Proceed to Phase D only if all checks pass.**

---

## Phase D: Component Mounting (~20 min)

Mount all electronics and components into the base housing.

### Steps

1. **Mount ESP32 DevKit V1** on the +X side standoffs in the base housing using M2 screws. The ESP32 mount is at position (35, -25) inside the base, with 4 standoffs in a 23x58mm hole pattern. The micro-USB port should face the USB-C cutout (9mm x 3.5mm) in the base wall.

2. **Mount BME280 breakout** elevated approximately 20mm above the base floor on its sensor shelf at position (0, 75) near the wall. The sensor needs air circulation, not contact with the base floor. The shelf has a retention lip to hold the breakout board. Secure with M2 hardware if needed.

3. **Position fan** centered in the base housing at origin (0, 0), oriented to blow upward into the dome cavity. The fan sits in the 30mm floor opening with 4 M3 standoffs at 24mm spacing. Secure with M3 screws.

4. **Place humidifier piezo disc** in the humidifier well on the -X side of the base (position -35, 0). The well is a raised cylindrical wall -- 40mm diameter (from `parameters.scad`: `humidifier_reservoir_diameter=40`) x 25mm deep (`humidifier_reservoir_depth=25`). The well has a 1mm weep hole for overflow drainage. For testing, fill with distilled water to 15mm depth.

5. **Route all wires** through the cable channels in the base floor. The channels are 3mm wide x 2mm deep, connecting USB-C to ESP32, ESP32 to fan, ESP32 to BME280, and ESP32 to humidifier. Use small cable ties or hot glue to secure wires in channels. Keep wires below the platform support ledge at z=45mm.

6. **Place substrate platform** on the drainage ribs inside the base. The platform (140mm diameter) rests on the support ledge ring at z=45mm (r=67-70mm). The 6 drain slots (4mm x 20mm each, at 60-degree intervals) and 8 drainage ribs (at 45-degree intervals) should face up for proper moisture management.

### Go / No-Go Checkpoint D

- [ ] ESP32 mounted securely on +X side standoffs
- [ ] BME280 elevated ~20mm, not touching base floor
- [ ] Fan centered, blowing upward
- [ ] Humidifier disc seated in well on -X side
- [ ] All wires routed through channels, below platform ledge
- [ ] Platform seated flat on support ring

**Before proceeding to Phase E -- complete the safety verification below.**

---

> ## STOP -- Safety Verification Before Dome Assembly
>
> Before seating the dome for the first time with all electronics connected, you MUST verify the UV-C safety interlock one more time with the complete wiring in place.
>
> ### Pre-Dome Interlock Test
>
> 1. Connect the USB-C PD power adapter (5V rail) and the ESP32 micro-USB cable.
> 2. Wait for the ESP32 to boot (serial monitor should show `[Init]` startup messages and the "Void Core" ASCII banner).
> 3. **Seat the dome** on the base. Verify the alignment notch (5mm wide x 3mm deep) registers with the base notch.
> 4. Trigger a UV-C sterilization cycle: **press and hold the button for 3 seconds** (long press).
> 5. The red indicator LED (GPIO 2) should light, confirming UV-C is active.
> 6. **Carefully lift the dome off the base.**
> 7. The red indicator LED should **immediately turn off** -- the reed switch opened, breaking the UV-C circuit.
> 8. **Replace the dome.** UV-C should NOT restart automatically (requires a new 3-second button hold to trigger).
>
> ### If the interlock fails:
>
> - **Red LED stays on with dome removed:** IMMEDIATELY disconnect USB power. Check reed switch wiring, magnet alignment, and MOSFET Q3 connections. The reed switch must be wired IN SERIES in the UV-C power path, not just as a GPIO input.
> - **Red LED never turns on:** Check GPIO 27 wiring, Q3 MOSFET gate resistor (220 ohm), and 5V rail power.
> - **DO NOT proceed to Phase E until this test passes.**

---

## Phase E: Dome Assembly (~5-10 min)

### Steps

1. **If using split dome:** Apply medium CA (cyanoacrylate) glue to the alignment step ring on the lower half. Press the upper half firmly onto the lower half, aligning the step ring. Hold for 30 seconds. Apply accelerator spray to the visible joint. Let cure for 5 minutes before handling.

2. **Insert 4 vent caps** into the dome exhaust holes. The caps have a 16mm outer flange and 12mm insertion body with snap-fit tabs. Push each cap inward until the flange seats flush against the dome exterior surface. The caps should hold by friction -- if they fall out, a small dot of CA glue on the snap tab will secure them.

3. **Seat dome onto base.** Align the dome's alignment notch (5mm wide, `alignment_notch_width=5` from `parameters.scad`) with the matching notch on the base rim. The dome seating lip (2.0mm height, 2.0mm inset from `dome_seating_lip_height` and `dome_seating_lip_inset`) should drop into the base seating channel (2.0mm deep x 2.0mm wide from `dome_seating_channel_depth` and `dome_seating_channel_width`). If using the optional silicone gasket O-ring (203mm ID, 2mm cross-section), install it in the gasket groove (1.5mm deep x 2.0mm wide) before seating the dome.

4. **VERIFY dome stability:** The dome should not wobble on the base. Lift and re-seat the dome 3-4 times -- the fit should be repeatable and consistent. The total assembled height should be approximately 254mm (from `parameters.scad`: `total_height=254`).

### Go / No-Go Checkpoint E

- [ ] Split dome halves glued and cured (if applicable)
- [ ] All 4 vent caps seated flush
- [ ] Dome seats firmly in base channel with alignment notch registered
- [ ] No wobble -- dome sits stable and level
- [ ] Assembled height approximately 254mm (10.0")

---

## Post-Assembly: First Power-On

With the dome seated and all checks passing:

1. Connect ESP32 via micro-USB to a computer running PlatformIO.
2. Open serial monitor (115200 baud) to verify boot messages.
3. Connect USB-C PD adapter for the 5V component rail.
4. Test each subsystem using the button:
   - **Short press:** Cycles light modes (Void Glow --> UV Only --> Blue Only --> Off).
   - **Long press (3 sec):** Triggers UV-C sterilization (15-minute cycle). Red indicator should light.
5. Open a web browser and connect to the ESP32 WiFi AP:
   - SSID: `VoidCore`
   - Password: `voidgrows`
   - Dashboard: `http://192.168.4.1`
6. Verify sensor readings on the web dashboard -- temperature, humidity, and pressure should update every 30 seconds.

See [firmware/BENCH-TEST.md](firmware/BENCH-TEST.md) for the full 9-test bench validation procedure.

---

## Wiring Quick Reference

For complete circuit diagrams, see [firmware/WIRING.md](firmware/WIRING.md).

| GPIO | Function | MOSFET | Gate Resistor |
|---|---|---|---|
| 21 | BME280 SDA | -- | -- |
| 22 | BME280 SCL | -- | -- |
| 25 | UV-A LEDs | Q1 (IRLZ44N) | 220 ohm |
| 26 | Blue LEDs | Q2 (IRLZ44N) | 220 ohm |
| 27 | UV-C LED | Q3 (IRLZ44N) | 220 ohm |
| 14 | Fan PWM | Q4 (IRLZ44N) | 220 ohm |
| 13 | Humidifier | Q5 (IRLZ44N) | 220 ohm |
| 16 | Reed switch | -- | -- (internal pull-up) |
| 17 | Button | -- | -- (internal pull-up) |
| 2 | Red indicator | -- | 220 ohm (LED current limiting) |

---

*Part of the Void Blueprints documentation.*
*See [BOM-CHECKLIST.md](BOM-CHECKLIST.md) for the complete parts list.*
*See [firmware/WIRING.md](firmware/WIRING.md) for full circuit diagrams.*
*Generated from Phase 12 Plan 02 -- Assembly Guide*
*Last updated: 2026-02-22*

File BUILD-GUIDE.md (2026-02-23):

# The Void -- Open-Source Build Guide

> Complete build documentation for community builders printing their own Void mushroom cultivation dome.
> This guide covers everything from STL file preparation through final assembly and testing.
> For electronic component sourcing, see PARTS-GUIDE.md. For firmware details, see FIRMWARE-DOCS.md.

---

## 1. Introduction & Overview

### What You're Building

**The Void** is a UV-lit mushroom cultivation dome -- a sealed growing chamber that doubles as a living art piece. It houses a pre-inoculated substrate block inside a smoked dome on a matte black base, illuminated by UV-A and blue LEDs. USB-C powered. No moving parts.

The completed dome measures **8.0" (203mm) diameter x 10.0" (254mm) total height** and sits on any desk, shelf, or nightstand.

### What's Included in Void Blueprints

Void Blueprints is the free, open-source package that includes:

- **STL files** for all printable parts (dome, base, platform, vent caps)
- **Pre-configured 3MF files** with optimized print settings for PrusaSlicer and Cura
- **STEP files** for community modifications and remixes
- **This build guide** covering print settings, tools, and step-by-step assembly

### What You'll Need to Buy Separately

The 3D-printed parts are only the enclosure. You will also need:

- **Electronics** -- LEDs, driver ICs, reed switch, button, USB-C connector, PCB, and passive components (~$30-45 sourced from AliExpress). See PARTS-GUIDE.md for a complete sourcing guide.
- **Hardware** -- silicone gasket, rubber feet, neodymium magnet, micropore tape (~$3-5)
- **Filament** -- PETG recommended (~$11-12 for all parts)

### Estimated Build Time

| Phase | Time |
|---|---|
| 3D printing (all parts) | 23-32 hours |
| Post-processing (optional) | 1-2 hours |
| Electronics assembly | 1-2 hours |
| Final assembly | 1-2 hours |
| **Total** | **~26-38 hours** (mostly unattended printing) |

### Estimated Total Cost

| Category | Cost |
|---|---|
| PETG filament (~380g) | ~$11.50 |
| Electronics and components | ~$30-45 |
| **Total (complete base Void)** | **~$40-55** |

### Build Variants

This guide covers three build options:

| Variant | Description | Electronics? |
|---|---|---|
| **The Void** (full build) | Complete cultivation dome with UV-A, blue, and UV-C LEDs, mode button, and USB-C power | Yes -- full electronics |
| **Dark Dome** (no electronics) | Same physical shell, no lighting or electronics. Ideal for bioluminescent species or budget builds | No electronics |
| **Void Core** (advanced) | Smart dome with Raspberry Pi, sensors, active humidity, and fan. See separate Void Core build guide | Advanced electronics |

This guide covers **The Void** (full build) and notes where the **Dark Dome** diverges. The Void Core is documented separately.

---

## 2. STL File Inventory

All files are available in the Void Blueprints repository. Download the complete package or individual files as needed.

### Printable Parts

| File | Description | Qty | Filament (g) | Print Time (est.) | Notes |
|---|---|---|---|---|---|
| `void-dome-full.stl` | Complete dome shell, 203mm diameter x 165mm tall, 2mm wall | 1 | ~150g | 12-16 hours | Single piece; fits 220x220mm beds |
| `void-dome-split-upper.stl` | Upper dome half (hemisphere section) | 1 | ~90g | 7-10 hours | For printers with <210mm bed width |
| `void-dome-split-lower.stl` | Lower dome half (vertical sidewall section) | 1 | ~60g | 5-6 hours | Pairs with upper split; glue together |
| `void-base.stl` | Complete base housing, 203mm diameter x 89mm tall | 1 | ~200g | 10-14 hours | Includes electronics bay, platform supports, vent slots |
| `void-platform.stl` | Substrate platform, 140mm diameter, perforated with drain slots | 1 | ~30g | 1-2 hours | Sits inside base; holds substrate block |
| `void-vent-cap.stl` | Snap-in exhaust vent cover for dome | 4 | ~3g each | 15-20 min each | Print all 4; holds micropore tape filter |

**Total filament for full build:** ~380g PETG

### Additional File Formats

| File | Format | Purpose |
|---|---|---|
| `void-dome-full.3mf` | 3MF | Dome with pre-configured print settings for PrusaSlicer and Cura (PETG on Ender 3 / Prusa i3) |
| `void-base.3mf` | 3MF | Base with pre-configured print settings |
| `void-assembly.step` | STEP | Full assembly CAD file for community modifications and remixes |

The `.3mf` files include recommended layer height, infill, support settings, and PETG material profiles pre-configured for Ender 3 and Prusa i3 printers. If you use one of these printers, the 3MF files are the easiest way to get started -- just open in your slicer and print.

---

## 3. Recommended Print Settings

### Printer Compatibility

**Minimum bed size: 220 x 220mm.** The dome is 203mm in diameter and must fit flat on the bed with margin.

The Void Blueprints are designed for mainstream FDM printers. Reference printers:

| Printer | Build Volume | Compatible? |
|---|---|---|
| Ender 3 / Ender 3 V2 | 220 x 220 x 250mm | Yes -- 8.5mm margin on each side |
| Prusa i3 MK3S+ / MK4 | 250 x 210 x 210mm | Yes |
| Prusa Mini (180 x 180mm) | 180 x 180 x 180mm | No (dome too large) -- use split files |
| Any printer with 220mm+ bed | Varies | Yes, if bed is at least 220mm in both X and Y |

**Smaller printers:** If your bed is under 210mm, use the split dome files (`void-dome-split-upper.stl` and `void-dome-split-lower.stl`). Print both halves and bond them with CA (super) glue or solvent welding along the split seam.

### Per-Part Print Settings

#### Dome Shell (`void-dome-full.stl`)

| Setting | Value | Notes |
|---|---|---|
| **Material** | PETG (smoked/dark tint preferred) | Humidity-resistant; semi-translucent for UV glow |
| **Layer height** | 0.2mm standard; 0.12mm for improved clarity | Finer layers reduce visible layer lines on dome |
| **Infill** | N/A -- dome is solid walls | 2mm wall thickness = 5 perimeters at 0.4mm nozzle |
| **Perimeters** | 5 (to achieve 2.0mm wall thickness) | 100% perimeters; no infill needed for thin-wall dome |
| **Print speed** | 50mm/s | Slower = better surface quality on curved surfaces |
| **Print orientation** | Open side down, apex up | Hemisphere prints cleanly from flat rim upward |
| **Supports** | Minimal -- apex only | Most of the dome stays within 45-degree overhang limit. Only the very top (~10-15mm near apex) may need light support. The apex has a 10mm flat to enable clean bridging. |
| **Bed temperature** | 70-80C | PETG requires heated bed for adhesion |
| **Nozzle temperature** | 230-245C | Adjust per your PETG brand; start at 235C |
| **Bed adhesion** | Glue stick or PEI sheet recommended | PETG sticks aggressively to bare glass and PEI; glue stick helps with release |

#### Base Housing (`void-base.stl`)

| Setting | Value | Notes |
|---|---|---|
| **Material** | PETG (primary) or PLA+ (acceptable) | PETG preferred for humidity resistance; PLA+ is easier to print but degrades in humid environments over time |
| **Layer height** | 0.2mm | Standard quality is fine for the base |
| **Infill** | 15% | Provides adequate rigidity without wasting filament |
| **Perimeters** | 4 (to achieve ~1.6mm minimum wall) | Base wall spec is 2.5mm; 4 perimeters at 0.4mm gives 1.6mm walls + infill fill |
| **Print speed** | 50mm/s | Standard speed |
| **Print orientation** | Bottom down (flat base on bed) | Excellent bed adhesion; internal features print upward |
| **Supports** | None | Base geometry is designed to print support-free |
| **Bed temperature** | 70-80C (PETG) / 60C (PLA+) | Adjust for your material |
| **Nozzle temperature** | 230-245C (PETG) / 200-215C (PLA+) | Adjust per brand |

#### Substrate Platform (`void-platform.stl`)

| Setting | Value | Notes |
|---|---|---|
| **Material** | PETG | Same material as base for consistency |
| **Layer height** | 0.2mm | Standard quality |
| **Infill** | 15% | Adequate for a platform |
| **Print speed** | 50mm/s | Standard |
| **Print orientation** | Flat side down | Simple flat part; no orientation concerns |
| **Supports** | None | Designed to print without supports |
| **Bed temperature** | 70-80C | Standard PETG |
| **Nozzle temperature** | 230-245C | Standard PETG |

#### Vent Caps (`void-vent-cap.stl` x4)

| Setting | Value | Notes |
|---|---|---|
| **Material** | PETG | Match dome material |
| **Layer height** | 0.2mm | Standard |
| **Infill** | 100% | Small parts; solid fill for strength |
| **Print speed** | 40mm/s | Slower for small detail |
| **Print orientation** | Flat side down | Print with the snap-fit tab facing up |
| **Supports** | None | Designed for support-free printing |
| **Bed temperature** | 70-80C | Standard PETG |
| **Nozzle temperature** | 230-245C | Standard PETG |

Print all 4 vent caps in a single batch to save time.

### Material Recommendations Summary

| Material | Recommended For | Why |
|---|---|---|
| **PETG (primary)** | All parts | Excellent humidity resistance (critical for 85-90% RH environment), semi-translucent for dome, moderate temperature resistance (80C), low warping |
| **PLA+** | Base housing only | Easier to print, better surface finish, but degrades in high humidity over time. Acceptable for the base since it is outside the humid chamber. NOT recommended for the dome. |
| **ABS** | Base housing (experienced printers) | High temp resistance, acetone-smoothable, but requires enclosure and produces toxic fumes during printing |
| **ASA** | Base housing or dome | UV-resistant alternative to ABS; similar properties but less widely available |
| **Clear PETG** | Dome (Dark Dome variant) | Semi-translucent for bioluminescent species viewing |

---

## 4. Tools & Materials Checklist

### Required Tools & Materials

You will need these to complete the build:

1. **3D printer** -- Ender 3 class or better, 220x220mm minimum bed
2. **PETG filament** -- approximately 400g total (smoked/dark tint for dome, black for base)
3. **Soldering iron + solder** -- for PCB and LED assembly
4. **Wire strippers** -- for preparing wire connections
5. **Flush cutters** -- for trimming leads and removing support material
6. **Small Phillips screwdriver** -- for PCB and component mounting
7. **Small flathead screwdriver** -- for prying and adjusting
8. **CA (super) glue** -- for securing the neodymium magnet in the dome rim pocket
9. **3M Micropore tape** -- for vent filters (blocks contaminant spores while allowing airflow)
10. **USB-C cable** -- standard USB-C to USB-A or USB-C to USB-C
11. **5V USB power adapter** -- any phone charger rated 5V/1A or higher

### Optional Tools & Materials (Post-Processing)

These improve the finished appearance but are not required for a functional build:

1. **Sandpaper** -- 200, 400, 800, and 1200 grit (progressive wet sanding for dome smoothing)
2. **Clear coat spray** -- Krylon UV-resistant clear gloss (2-3 light coats on dome for improved transparency)
3. **Matte black spray paint** -- primer + matte black for base exterior finish
4. **Smoke tint spray** -- VHT Nite-Shades or similar (if using clear PETG and you want a smoked dome look)

---

## 5. Pre-Print Checklist

Complete these steps before starting your first print:

1. **Verify bed size** -- confirm your printer bed is at least 220 x 220mm. The dome is 203mm in diameter and needs 8.5mm clearance on each side. If your bed is smaller than 210mm, use the split dome files instead.

2. **Level your bed** -- a level bed is critical for the large dome footprint. Run your printer's bed leveling routine. For manual tramming, check all four corners and the center.

3. **Load PETG filament** -- if you have not printed PETG before, review your printer's PETG temperature profile. PETG typically prints at 230-245C nozzle and 70-80C bed. It is more stringy than PLA but more durable.

4. **Run a test print** -- before committing to a 12-16 hour dome print, run a small test piece (a 50mm cube or calibration print) in PETG to verify bed adhesion and temperature settings on your specific printer.

5. **Clean the build plate** -- wipe with isopropyl alcohol. For PETG, apply a thin layer of glue stick to prevent the print from bonding too aggressively to glass or PEI surfaces.

6. **Verify PETG temperature profile** -- every PETG brand prints slightly differently. Start with 235C nozzle / 75C bed and adjust. If you see stringing, reduce nozzle temp by 5C. If you see poor layer adhesion, increase by 5C.

7. **Check filament quantity** -- ensure you have at least 400g of PETG available. Running out mid-print on the dome is not recoverable. Weigh your spool if unsure.

8. **Clear print schedule** -- the dome alone takes 12-16 hours. Plan to start the print when you can monitor the first few layers and let it run overnight or through the day.

---

## 6. Assembly Overview

### Assembly Flow

Follow this order for the smoothest build experience:

```
Print all parts
      |
      v
Post-process (optional: sand dome, paint base)
      |
      v
Install electronics in base (PCB, LEDs, USB-C, button, reed switch)
      |
      v
Install silicone gasket in base rim
      |
      v
Apply micropore tape to all vents
      |
      v
Install neodymium magnet in dome rim
      |
      v
Test electronics (power on, verify all light modes)
      |
      v
Seat dome on base
      |
      v
Done -- place a Void Pack and grow
```

### Estimated Assembly Time

- **Electronics assembly (Steps 1-12):** 1-2 hours (most time spent soldering)
- **Dome preparation (Steps 13-16):** 15-30 minutes
- **Final assembly and testing (Steps 17-22):** 30-45 minutes
- **Total:** 2-4 hours (excluding print time and post-processing)

### Cross-Section Reference Diagram

Refer to this diagram throughout assembly. It shows the internal layout and how all components fit together.

```
                          ___
                        /     \           <- Dome apex
                      /  (ExV)  \         <- Exhaust vent (x4 around this zone)
                    /             \
                   /               \
                  |   ~~~HUMID~~~   |     <- High-humidity growing zone (85-90% RH)
                  |                 |
                  |  +===========+  |
                  |  ||  FRUIT  ||  |     <- Mushroom fruiting bodies
                  |  || BODIES  ||  |
                  |  +===========+  |
                  |  |  VOID     |  |     <- Void Pack substrate block
                  |  |  PACK     |  |        (~4.5" W x 3" H, 1-2 lbs)
                  |  |  BLOCK    |  |
                  |  +-----+-----+  |
                  |  | platform  |  |     <- Substrate platform (5.5" / 140mm dia)
    Dome -------> |  +--+--+--+--+  |
    seated in --> ====[LED RING]====== <-- UV-A (395nm) + Blue (450nm) LEDs
    base channel  |     (Magnet^)   |     <- Magnet in dome lip / Reed switch in base
                  |                 |
               -->[InV]  PLENUM [InV]<--  <- Intake vents (x8) with micropore tape
                  |    (airflow)    |        Fresh air enters here
                  |  +-----------+  |
                  |  | ELECTR.   |  |     <- LED driver, UV-C LED (points up),
                  |  | [UV-C ^]  |  |        mode button, USB-C connector
                  |  | [BTN][USB]|  |
                  +--+-----------+--+
                    (  rubber feet  )     <- 4x silicone feet
               ========================     Desk surface
```

**Key dimensions:**
- Overall: 8.0" (203mm) wide x 10.0" (254mm) tall
- Dome: 6.5" (165mm) tall (including 1.0" / 25mm vertical sidewall)
- Base: 3.5" (89mm) tall
- Substrate platform: 5.5" (140mm) diameter, 0.5" (13mm) deep well
- Substrate clearance above block: ~5.5-6.0" (140-152mm) to dome apex
- LED ring position: at dome/base junction, angled 30 degrees upward
- UV-C LED position: in electronics bay, pointing upward through platform drain slots

---

## 7. Base Assembly (Steps 1-12)

### Step 1: Inspect Printed Base

**What:** Check the printed base housing for quality issues before assembly.

**How:** Examine the base for warping (set it on a flat surface -- it should sit flat without rocking). Look for stringing inside the electronics bay and around vent slots. Remove any loose stringing with flush cutters. Check that all 8 intake vent slots (15mm x 5mm each) are clear and open. Verify the dome seating channel (2mm deep groove around the top rim) is clean and even.

**Check:** Base sits flat on a table. All 8 intake vents are open. Electronics bay is clean and accessible. Dome seating channel has no blobs or stringing.

### Step 2: Install Rubber Feet

**What:** Attach four silicone rubber feet to the bottom of the base for desk stability.

**How:** Clean the base bottom with isopropyl alcohol. Peel the adhesive backing from each 12mm x 3mm silicone foot. Place one foot near each edge of the base bottom, spaced evenly around the circumference (roughly at 12, 3, 6, and 9 o'clock positions). Press firmly for 10 seconds each.

**Check:** All four feet are firmly attached. Base sits level and does not wobble on a flat surface.

### Step 3: Install Substrate Platform

**What:** Place the substrate platform in the base.

**How:** Orient the platform with the perforated (drain slot) side facing up. Lower it into the recessed well inside the base. It should sit level on the molded supports inside the base, approximately 0.5" (13mm) above the airflow plenum.

**Check:** Platform sits level in the base. Drain slots are visible and unobstructed. Platform does not rock or tilt.

### Step 4: Install PCB in Electronics Bay

**What:** Mount the assembled PCB in the electronics bay at the bottom of the base.

**How:** The electronics bay is the lower compartment of the base, beneath the airflow plenum. Position the PCB (50mm x 30mm, 2-layer) so the USB-C connector aligns with the rectangular cutout (9mm x 3.5mm) at the rear-center of the base. Secure the PCB with M3 screws into the printed screw bosses (3.2mm holes), or friction-fit it against the printed retention features. Ensure the PCB sits flat and is not stressed or bent.

**Check:** PCB is seated flat in the electronics bay. USB-C port aligns with the rear cutout. PCB does not shift when you press on it.

### Step 5: Solder LED Ring

**What:** Build the LED ring with 12 LEDs (6 UV-A + 6 Blue) in alternating configuration.

**How:** The LED ring PCB holds 12 5050 SMD LEDs in a circular arrangement. Alternate UV-A (395nm) and Blue (450nm) LEDs around the ring: UV-A, Blue, UV-A, Blue, and so on. All LEDs should be angled approximately 30 degrees upward (toward the dome interior when assembled). Solder each LED observing correct polarity -- the cathode marking on the LED must match the PCB pad marking. Each LED draws 20mA at 3.0-3.4V forward voltage. The 6 UV-A and 6 Blue LEDs are wired as two strings of 6, driven by the PT4115 constant-current LED driver IC on the PCB.

**Check:** All 12 LEDs are soldered with correct polarity. No solder bridges between pads. Visual inspection: all LEDs seated flat and evenly spaced.

### Step 6: Mount LED Ring

**What:** Install the LED ring at the dome/base junction.

**How:** Position the LED ring PCB on the mounting posts at the top of the base housing, just inside the dome seating channel. The LEDs should point upward at approximately 30 degrees into the dome interior. Secure with M3 screws into the printed posts, or use hot glue if your print does not have clean screw holes. Connect the LED ring wires to the main PCB below (two connections: UV-A string and Blue string).

**Check:** LED ring is firmly mounted. LEDs point upward into the dome area. Wires routed cleanly to the electronics bay below.

### Step 7: Install UV-C LED

**What:** Install the single UV-C sterilization LED pointing upward through the platform drain slots.

**How:** The UV-C LED (275nm, 3535 SMD package) mounts on the main PCB or a small daughter board in the electronics bay. It must point directly upward through the drain slots in the substrate platform so its 120-degree beam covers the dome interior. The UV-C LED operates at 6.5V (via a boost converter from 5V) and draws 250-350mA when active. It is wired through the reed switch (safety interlock) so it can only receive power when the dome magnet closes the reed switch.

**Check:** UV-C LED is mounted pointing straight up. When you look down through the substrate platform drain slots, you can see the UV-C LED below.

### Step 8: Install Reed Switch

**What:** Position the reed switch for the UV-C safety interlock.

**How:** The reed switch (normally-open, glass body) must be positioned in the base near the dome seating rim, within 5mm of where the dome's embedded magnet will sit when the dome is seated. Secure the reed switch with hot glue in the channel or slot designed for it in the base top rim area. The reed switch is wired in series with the UV-C LED power line -- this is a hardware interlock, not software. When the dome magnet is within 5mm, the reed switch closes and completes the UV-C power circuit.

**Check:** Reed switch is firmly positioned near the dome seating rim. Reed switch leads are connected to the UV-C power circuit on the PCB.

### Step 9: Install Mode Button

**What:** Install the button for cycling light modes and activating UV-C.

**How:** Insert the 12mm waterproof tactile switch into the circular cutout on the front of the base. The button should sit flush with or slightly proud of the base exterior. Connect the button leads to the mode logic circuit on the PCB. The button has two functions: tap to cycle light modes (Void Glow, UV Only, Blue Only, Off) and press-and-hold for 3 seconds to start a UV-C sterilization cycle.

**Check:** Button clicks cleanly when pressed. Button is accessible from the outside of the base. Button wires connected to PCB.

### Step 10: Install USB-C Connector

**What:** Mount the USB-C power input connector.

**How:** The USB-C receptacle sits in the rectangular cutout (9mm x 3.5mm) at the rear-center of the base, recessed 3mm into the housing. If the USB-C connector is on the main PCB, it should already be aligned from Step 4. If it is a separate connector, mount it in the cutout and wire it to the PCB. The USB-C PD sink IC (CH224K or IP2721) on the PCB negotiates 5V from any USB-C source.

**Check:** USB-C port is accessible from the rear of the base. A USB-C cable plugs in and seats fully. Port is recessed and protected.

### Step 11: Wire Connections

**What:** Complete all internal wiring between components.

**How:** Refer to the wiring diagram below and connect all remaining wires. Use the PCB's solder pads or screw terminals as appropriate.

```
USB-C port
    |
    v
[USB-C PD Sink IC] --> 5V rail
    |
    +---> [LED Driver] ---> UV-A LED string (6x series)
    |         |
    |         +-----------> Blue LED string (6x series)
    |
    +---> [555 Timer #1] ---> 12h cycle control (enables/disables LED driver)
    |
    +---> [Button] ---> [Mode logic] ---> LED driver enable/channel select
    |                        |
    |                        +---> [3-sec hold detect] ---> UV-C trigger
    |
    +---> [Reed switch] ---> [555 Timer #2] ---> UV-C LED
    |                                             (interlock in series)
    |
    +---> [Red indicator LED] (parallels UV-C power)
```

Key wiring notes:
- The reed switch is wired **in series** with the UV-C LED power. This is a hardware safety interlock -- UV-C physically cannot receive power without the dome magnet closing the reed switch.
- The red indicator LED is wired in parallel with the UV-C power line. It lights whenever UV-C is active.
- Two NE555 timer ICs handle: (1) 12-hour on/off light cycle, and (2) 15-minute UV-C auto-shutoff.
- All components operate from a single 5V rail supplied through the USB-C connector.

**Check:** Trace every wire visually. Verify the reed switch is in series with UV-C (not bypassed). Verify the red LED is connected. Verify button connections. No loose or floating wires.

### Step 12: Install Red Indicator LED

**What:** Mount the UV-C active indicator LED next to the mode button.

**How:** Install the 3mm red through-hole LED in the small hole next to the button cutout on the base front. The LED should be visible from outside the base. It is wired in parallel with the UV-C LED power -- it lights whenever a UV-C sterilization cycle is running, warning users not to remove the dome.

**Check:** Red LED is visible from outside the base. When UV-C activates, this LED will light up.

---

## 8. Dome Preparation (Steps 13-16)

### Step 13: Inspect Printed Dome

**What:** Check the dome print quality before proceeding.

**How:** Examine the dome for good layer adhesion -- run your fingernail across the layers; they should not separate or feel like they are peeling. Check overall dome roundness by rolling it gently on a flat surface. Verify all 4 exhaust vent holes (12mm diameter each) near the apex are clean and open. Check the dome seating rim at the bottom -- it should be flat and even, with the magnet pocket (6.5mm diameter x 2.5mm deep) clearly visible.

**Check:** Layers are well-bonded. Dome is reasonably round (no major warping). All 4 exhaust vents are open. Seating rim is flat. Magnet pocket is present and clean.

### Step 14: (Optional) Post-Process Dome

**What:** Sand and finish the dome for improved appearance and transparency.

**How:** This step is optional but significantly improves the dome's appearance.

1. **Wet sand** the dome exterior starting with 200-grit sandpaper, working progressively through 400, 800, and 1200 grit. Wet sanding reduces dust and produces a smoother finish. Sand in circular motions, applying even pressure.
2. **Dry thoroughly** after sanding.
3. **Apply clear coat** -- spray 2-3 light coats of Krylon UV-resistant clear gloss, allowing 15 minutes between coats. Hold the can 10-12 inches from the surface. Multiple thin coats are better than one thick coat.
4. **Test UV glow** -- before clear coating, place a UV-A LED inside the dome in a dark room to verify the UV glow effect through the printed walls. This confirms your PETG transmits enough light. Do this test BEFORE post-processing, so you can adjust if needed.

**Check:** Dome surface is smoother than raw print. Clear coat is even without drips or pooling. UV glow is visible through dome walls.

### Step 15: Install Neodymium Magnet

**What:** Press-fit the dome magnet into the rim pocket for the UV-C safety interlock.

**How:** Apply a small drop of CA (super) glue inside the magnet pocket (6.5mm diameter x 2.5mm deep) in the dome's seating rim. Press a 6mm x 2mm neodymium disc magnet (N35 grade) into the pocket. The magnet should sit flush with or slightly below the rim surface. Hold in place for 30 seconds while the glue sets.

**Important:** Before gluing, test that the magnet activates the reed switch in the base. Hold the magnet near the reed switch location -- you should hear a faint click or be able to verify closure with a multimeter. If the magnet does not activate the reed switch from the dome rim pocket position, the reed switch may need to be repositioned closer (within 5mm).

**Check:** Magnet is firmly glued in the pocket. Magnet does not protrude above the rim surface. Magnet activates the reed switch when the dome is seated on the base.

### Step 16: Apply Micropore Tape to Exhaust Vents

**What:** Install contamination barrier filters on the dome's exhaust vents.

**How:** Cut 4 small squares of 3M Micropore tape, each large enough to fully cover a 12mm exhaust vent hole. Apply one piece over each of the 4 exhaust vents on the dome exterior. If your dome has snap-in vent cap holders, apply the tape to the vent cap disc, then snap it into position. The micropore tape blocks contaminant spores (particles > 0.3 micrometers) while allowing humid air to pass through.

**Check:** All 4 exhaust vents are covered with micropore tape. Tape is smooth and fully adhered -- no gaps or lifted edges.

---

## 9. Final Assembly & Testing (Steps 17-22)

### Step 17: Apply Micropore Tape to Base Intake Vents

**What:** Install contamination barrier filters on the base's intake vents.

**How:** Cut 8 small strips of 3M Micropore tape, each large enough to cover one intake vent slot (15mm x 5mm). Apply one strip over each of the 8 intake vent slots around the base perimeter. Press firmly to ensure full adhesion.

**Check:** All 8 intake vents are covered with micropore tape. No gaps or loose edges.

### Step 18: Install Silicone Gasket

**What:** Press-fit the silicone gasket ring into the base seating channel.

**How:** The base top rim has a 2.0mm wide x 1.5mm deep groove (the dome seating channel). Press the silicone gasket ring (190mm ID, 1.5mm cross-section, food-grade silicone) into this groove. Work it in evenly around the full circumference. The gasket creates a humidity seal between the dome and base while still allowing easy dome removal.

**Check:** Gasket is fully seated in the groove all the way around. Gasket does not pop out when you press on it. Gasket surface is slightly proud of the rim (this is correct -- it compresses when the dome is seated).

### Step 19: Seat Dome on Base

**What:** Place the dome onto the base for the first time.

**How:** Align the dome's orientation notch with the corresponding notch on the base rim. This single alignment notch ensures the dome always seats in the same orientation (important for vent alignment and magnet/reed switch positioning). Lower the dome straight down onto the base. Press down firmly until the gasket compresses and the dome sits flush in the seating channel.

**Check:** Dome sits evenly on the base with no gaps visible around the rim. Dome does not wobble. You can feel the gasket providing a slight seal. The dome lifts straight off with gentle upward force -- no sticking or binding.

### Step 20: Connect Power

**What:** Power up the Void for the first time.

**How:** Plug a USB-C cable into the port on the rear of the base. Connect the other end to any 5V USB power adapter rated 1A or higher (any standard phone charger will work). The base Void draws only 0.8-1.1W during normal operation -- well under the USB 2.0 500mA/2.5W limit.

**Check:** USB-C cable seats fully in the port. Power adapter is connected and turned on.

### Step 21: Test Light Modes

**What:** Verify all light modes work correctly.

**How:** Tap the mode button to cycle through the four light modes:

| Mode | Button Press | UV-A (purple) | Blue | What You See |
|---|---|---|---|---|
| 1. Void Glow | Tap (default) | ON | ON | Purple + blue glow inside dome |
| 2. UV Only | Tap | ON | OFF | Purple-only glow |
| 3. Blue Only | Tap | OFF | ON | Blue-only light |
| 4. Off | Tap | OFF | OFF | No light |

Cycle through all four modes. In a darkened room, verify the UV-A purple glow is visible through the dome walls. The 12-hour timer circuit will automatically cycle the lights (12h on, 12h off) during normal use.

**Check:** All four modes cycle correctly with button taps. LEDs illuminate inside the dome. UV-A glow is visible through the dome wall. Modes cycle in order: 1, 2, 3, 4, 1.

### UV-C SAFETY WARNING

```
===========================================================================
  WARNING: UV-C RADIATION HAZARD

  The UV-C LED (275nm) emits germicidal ultraviolet radiation that is
  harmful to eyes and skin. The dose delivered inside the dome (90-180
  mJ/cm2) is 15-30x the ACGIH 8-hour exposure limit for humans.

  - NEVER look directly at the UV-C LED when powered.
  - ALWAYS ensure the dome is fully seated during sterilization cycles.
  - The hardware interlock (reed switch + magnet) prevents UV-C from
    activating without the dome in place, but YOU MUST verify this
    works correctly in Step 22 before regular use.
  - A red indicator LED on the base lights during the entire UV-C
    cycle. If the red LED is on, do NOT remove the dome.
  - If the safety interlock fails (UV-C activates with dome removed),
    IMMEDIATELY disconnect USB power and do not use until repaired.
===========================================================================
```

### Step 22: Test UV-C Safety Interlock

**What:** Verify the UV-C sterilization system and safety interlock function correctly. This is the most important test in the entire build.

**How:**

1. **Ensure the dome is seated on the base** (from Step 19).
2. **Press and hold the mode button for 3 seconds.** The red indicator LED on the base should light up, indicating a UV-C sterilization cycle has started. The UV-C LED inside the base is now active (you will not see its light -- 275nm is invisible to the human eye, and the dome blocks UV-C anyway).
3. **Verify the red LED stays on.** The 15-minute cycle timer (NE555) will automatically shut off UV-C after 15 minutes.
4. **TEST THE INTERLOCK: While the red LED is on (UV-C active), carefully lift the dome off the base.** The UV-C LED should **immediately** stop, and the red indicator LED should turn off. This confirms the hardware interlock (reed switch) is working -- removing the dome breaks the magnet-reed switch connection and cuts power to the UV-C LED.
5. **Replace the dome.** The UV-C cycle should NOT automatically restart (it requires a new 3-second button hold to start a new cycle).

**If the interlock fails** (UV-C continues after dome removal, or the red LED stays on with the dome removed): **STOP. Disconnect USB power immediately.** Check the reed switch position (must be within 5mm of the dome magnet when seated), verify the reed switch is wired in series (not bypassed), and check the magnet orientation. Do not use UV-C until the interlock is verified working.

**Check:** UV-C activates with 3-second button hold (red LED lights). UV-C stops immediately when dome is removed (red LED turns off). UV-C does not restart when dome is replaced (requires new button hold). This confirms the hardware safety interlock is functional.

---

## 10. Troubleshooting

### Common Issues and Fixes

| Problem | Likely Cause | Fix |
|---|---|---|
| **Dome doesn't seat properly on base** | Print tolerance too tight, or gasket not seated correctly | Sand the dome rim lightly with 200-grit sandpaper to add clearance (0.3-0.5mm needed). Verify gasket is fully seated in the groove and not bunched up. |
| **LEDs don't light up** | Incorrect LED polarity, cold solder joint, or bad connection to driver | Check LED polarity on every LED -- cathode mark must match PCB pad. Reflow any solder joints that look dull or cold. Verify the LED driver IC is receiving 5V. Test with a multimeter: 3.0-3.4V across each LED when powered. |
| **UV-C doesn't activate (red LED stays off)** | Reed switch not detecting dome magnet, or magnet too far from reed switch | Verify magnet is installed in dome rim pocket. Check reed switch position -- must be within 5mm of magnet when dome is seated. Test reed switch with multimeter: should show continuity when magnet is held close. Check that reed switch is wired in series with UV-C power. |
| **Dome fogs excessively (can't see inside)** | Micropore tape blocking too much airflow, or vents are covered | Verify all 4 exhaust vents and 8 intake vents have micropore tape applied (not solid tape or stickers). Micropore tape is semi-permeable -- if condensation is extreme, try using a single layer of tape instead of doubled-up tape. Some condensation is normal at 85-90% humidity. |
| **Button doesn't cycle modes** | Bad button connection, or button not making contact | Verify button wires are connected to the correct PCB pads. Test the button with a multimeter for continuity when pressed. If the button feels mushy, ensure it is fully seated in the 12mm cutout. |
| **Dome too dark for UV glow to show** | PETG filament too opaque, or too many perimeters | Try a different PETG brand with higher translucency. Print with 4 perimeters instead of 5 (1.6mm wall instead of 2.0mm -- slightly thinner but more translucent). Alternatively, use clear PETG and apply smoke tint spray (VHT Nite-Shades) for controllable tint level. |
| **UV-C activates without dome seated** | Reed switch stuck closed, or wiring bypasses interlock | **SAFETY ISSUE -- disconnect power immediately.** Check that the reed switch is normally-open type. Verify no metallic objects near the reed switch are holding it closed. Verify wiring: reed switch must be in series with UV-C power, not bypassed. Replace reed switch if stuck. |
| **Base warped (doesn't sit flat)** | Print bed not level, or part cooled unevenly | Reprint with a properly leveled bed. Use a heated bed at 70-80C for PETG. Ensure the print area is draft-free during printing. If minor warping, place the base on a flat surface and heat the bottom with a heat gun to gently flatten. |
| **Dome layers separating / delaminating** | Print temperature too low, or PETG moisture absorption | Increase nozzle temperature by 5-10C. Dry your PETG filament (4 hours at 65C in a food dehydrator or filament dryer). PETG absorbs moisture from the air, which causes poor layer adhesion and popping/bubbling during printing. |

### When to Reprint

- **Dome:** Reprint if layers are visibly separating, if the dome is significantly out of round (noticeable wobble when seated), or if the magnet pocket is damaged.
- **Base:** Reprint if warping prevents the base from sitting flat, if vent slots are clogged and cannot be cleared, or if screw bosses are cracked.
- **Platform:** Reprint if drain slots are clogged or the platform does not sit level in the base.
- **Vent caps:** Reprint if the snap-fit is too loose or too tight. Adjust scale by +/- 2% in your slicer to fine-tune the fit.

### Getting Help

- File issues and ask questions in the Void Blueprints repository
- Join the community discussion for build tips and troubleshooting help
- Share your completed build -- every printed Void is a contribution to the community

---

*Build Guide version: 1.0*
*Part of the Void Blueprints open-source package.*

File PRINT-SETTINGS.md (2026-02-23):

# The Void -- Print Settings Guide

Recommended 3D print settings for all Void dome parts. Follow these settings to minimize failed prints and wasted filament.

See [PARTS-MANIFEST.md](PARTS-MANIFEST.md) for the full parts list, export scripts, and print order.

## Material Recommendation

**PETG (recommended)** -- Humidity resistance, slight flex for snap-fits, good layer adhesion on curved surfaces. The dome operates in a high-humidity environment (85-95% RH); PETG handles this without degradation.

**PLA (acceptable for test prints)** -- Cheaper and easier to print, but will soften and degrade in sustained high-humidity conditions. Use for initial fit testing only.

**ABS (not recommended)** -- Excessive warping on large curved surfaces like the dome hemisphere. Do not use.

## General Slicer Settings

| Setting | Value |
|---|---|
| Material | PETG |
| Nozzle temperature | 235 C |
| Bed temperature | 70 C |
| First layer height | 0.28mm (for adhesion) |
| Print speed | 50mm/s (curved surfaces) |
| Detect thin walls | Enabled |
| Infill pattern | Gyroid (unless noted) |

## Per-Part Print Settings

### 1. Substrate Platform

| Setting | Value |
|---|---|
| **Dimensions** | 140mm diameter x 8mm height |
| **Layer height** | 0.2mm |
| **Infill** | 20% gyroid |
| **Supports** | None |
| **Orientation** | Print flat (bottom surface on bed) |
| **Estimated filament** | ~30g PETG |
| **Estimated time** | ~1.5 hours |

**Notes:** Smallest and fastest part. Print first as a calibration test. Drain slots and drainage ribs should print cleanly without supports.

### 2. Vent Cap Set (4x)

| Setting | Value |
|---|---|
| **Dimensions** | 4x 16mm diameter x 4mm height (2x2 grid) |
| **Layer height** | 0.16mm (finer for smooth snap tabs) |
| **Infill** | 100% (small parts, solid fill) |
| **Supports** | None |
| **Orientation** | Print flat, flange side down |
| **Estimated filament** | ~12g PETG total (all 4 caps) |
| **Estimated time** | ~45 minutes |

**Notes:** Fine layer height (0.16mm) is important for smooth snap-fit tabs. These tabs insert into the dome exhaust vent holes and need clean edges for a secure friction fit. Solid infill since the parts are very small.

### 3. Base Housing

| Setting | Value |
|---|---|
| **Dimensions** | 203mm diameter x 89mm height |
| **Layer height** | 0.2mm |
| **Infill** | 25% gyroid |
| **Supports** | Yes -- tree supports recommended |
| **Orientation** | Print upright (open-top facing up) |
| **Estimated filament** | ~200g PETG |
| **Estimated time** | ~12 hours |

**Notes:** Supports are needed for the USB-C cutout and button hole overhangs in the base walls. Use tree supports (available in Cura, OrcaSlicer, PrusaSlicer 2.7+) to minimize interior contact marks. The seating channel at the top rim should print cleanly as a downward-facing overhang is avoided in the upright orientation.

### 4. Dome Full (one-piece option)

| Setting | Value |
|---|---|
| **Dimensions** | 203mm diameter x 165mm height |
| **Layer height** | 0.2mm |
| **Infill** | 15% gyroid |
| **Supports** | None (hemisphere self-supports above 45 degrees) |
| **Orientation** | Print base-down (open end on bed) |
| **Estimated filament** | ~150g PETG |
| **Estimated time** | ~14 hours |

**Notes:** Requires a printer with 220mm+ build plate height (250mm recommended). The hemisphere geometry naturally self-supports -- no overhang exceeds 45 degrees until near the apex, which has a 10mm flat bridging zone. Print with the open end (seating lip) on the build plate for maximum stability.

### 5. Dome Upper (split option)

| Setting | Value |
|---|---|
| **Dimensions** | ~203mm diameter x ~95mm height |
| **Layer height** | 0.2mm |
| **Infill** | 15% gyroid |
| **Supports** | None |
| **Orientation** | Print cut-face down |
| **Estimated filament** | ~90g PETG |
| **Estimated time** | ~8 hours |

**Notes:** The flat cut face provides a stable base for printing. Fits on a standard 220x220mm bed. The alignment step ring on the cut face interfaces with the dome lower half.

### 6. Dome Lower (split option)

| Setting | Value |
|---|---|
| **Dimensions** | ~203mm diameter x ~70mm height |
| **Layer height** | 0.2mm |
| **Infill** | 15% gyroid |
| **Supports** | None |
| **Orientation** | Print base-down (seating lip on bed) |
| **Estimated filament** | ~60g PETG |
| **Estimated time** | ~5 hours |

**Notes:** The shorter half of the split dome. Print with the seating lip (open end) on the bed for stability. The alignment step ring at the top interfaces with the dome upper half.

## Split vs Full Dome Decision Guide

| Criterion | Full Dome | Split Dome |
|---|---|---|
| **Build volume required** | 220 x 220 x 250mm+ | 220 x 220 x 220mm (standard) |
| **Structural strength** | Stronger (no joint) | Requires glue joint |
| **Print count** | 1 print | 2 prints |
| **Total filament** | ~150g | ~150g (90 + 60) |
| **Total time** | ~14 hours | ~13 hours (8 + 5) |
| **Assembly** | None | Glue with medium CA + accelerator on alignment step ring |

**Recommendation:**
- If your printer has 220x220x250mm+ build volume, print the **full dome** for maximum strength (no glue joint).
- If your printer is 220x220x220mm (standard), use the **split dome** option. Apply medium CA (cyanoacrylate) glue with accelerator spray on the 1mm alignment step ring for a strong, invisible bond.

## Total Materials Estimate

### Option A: Full Dome Build

| Part | Filament |
|---|---|
| Substrate Platform | ~30g |
| Vent Cap Set (4x) | ~12g |
| Base Housing | ~200g |
| Dome Full | ~150g |
| **Total** | **~392g PETG** |

### Option B: Split Dome Build

| Part | Filament |
|---|---|
| Substrate Platform | ~30g |
| Vent Cap Set (4x) | ~12g |
| Base Housing | ~200g |
| Dome Upper | ~90g |
| Dome Lower | ~60g |
| **Total** | **~392g PETG** |

**Total filament:** ~380-440g PETG (one 1kg spool is sufficient with margin for test prints)

**Total print time:** ~30-40 hours unattended (varies by printer speed, infill density, and slicer settings)

## Additional Supplies

| Item | Purpose |
|---|---|
| Medium CA glue + accelerator | Split dome joint (if using split option) |
| Isopropyl alcohol (IPA) | Build plate cleaning for PETG adhesion |
| Glue stick or PEI sheet | Bed adhesion for PETG |
| Sandpaper (220-400 grit) | Optional: smooth any support contact marks on base housing |

---
*Generated from Phase 12 Plan 01 -- Print Settings Guide*
*Last updated: 2026-02-22*

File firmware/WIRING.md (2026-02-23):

# The Void -- ESP32 Prototype Wiring Guide

> Circuit wiring reference for the Void Core ESP32 DevKit V1 prototype.
> For production Void Core (Pi Zero W 2), see FIRMWARE-DOCS.md Section 4.
> For base Void hardware-only circuit, see FIRMWARE-DOCS.md Section 2.

---

## Pin Assignments

ESP32 DevKit V1 (38-pin) GPIO mapping for all Void Core prototype peripherals.

| GPIO | Function | Direction | Signal | Notes |
|---|---|---|---|---|
| 21 | BME280 I2C data (SDA) | Bidirectional | I2C SDA | 3.3V logic, external pull-up on breakout |
| 22 | BME280 I2C clock (SCL) | Output | I2C SCL | 3.3V logic, external pull-up on breakout |
| 25 | UV-A LED string enable | Output | Active HIGH | Drives N-channel MOSFET gate |
| 26 | Blue LED string enable | Output | Active HIGH | Drives N-channel MOSFET gate |
| 27 | UV-C trigger | Output | Active HIGH | Gated by reed switch in series on drain side |
| 14 | Fan PWM | Output | Hardware PWM (LEDC) | 25 kHz, 8-bit resolution |
| 13 | Humidifier enable | Output | Active HIGH | Drives N-channel MOSFET gate |
| 16 | Reed switch input | Input | Internal pull-up | LOW = dome seated (magnet closes reed switch) |
| 17 | Button input | Input | Internal pull-up | LOW = pressed |
| 2 | Red indicator LED | Output | Active HIGH | Built-in LED on most DevKits; UV-C warning |

---

## ASCII Wiring Diagram

```
                        +---------------------+
                        |   ESP32 DevKit V1   |
                        |                     |
                 3V3 ---|  3V3           GND  |--- GND bus
                        |                     |
    BME280 SDA  <------>| GPIO 21 (SDA)       |
    BME280 SCL  <-------| GPIO 22 (SCL)       |
                        |                     |
    UV-A MOSFET (220R)<-| GPIO 25             |
    Blue MOSFET (220R)<-| GPIO 26             |
    UV-C MOSFET (220R)<-| GPIO 27             |
                        |                     |
    Fan MOSFET (220R) <-| GPIO 14             |
    Hum. MOSFET (220R)<-| GPIO 13             |
                        |                     |
    Reed switch in ---->| GPIO 16             |
    Button in --------->| GPIO 17             |
                        |                     |
    Red LED (220R) <----| GPIO 2              |
                        |                     |
                    USB | 5V (USB)            |
                        +---------------------+

    === BME280 Breakout ===

    ESP32 3V3 -------> BME280 VIN
    ESP32 GND -------> BME280 GND
    ESP32 GPIO 21 ---> BME280 SDA  (I2C data, pull-ups on breakout)
    ESP32 GPIO 22 ---> BME280 SCL  (I2C clock, pull-ups on breakout)

    === UV-A LED String (6x 395nm, series via PT4115 driver) ===

    5V rail ---> [PT4115 LED driver] ---> UV-A LED+ (anode)
    UV-A LED- (cathode) ---> MOSFET drain (Q1)
    MOSFET source (Q1) ---> GND
    ESP32 GPIO 25 ---> 220R ---> MOSFET gate (Q1)

                  +5V
                   |
            [PT4115 driver]
                   |
          UV-A LED string (6x series)
                   |
             Drain |
        Q1 [IRLZ44N] MOSFET
             Source|
                   |
                  GND
        Gate <--- 220R <--- GPIO 25

    === Blue LED String (6x 450nm, series via PT4115 driver) ===

    5V rail ---> [PT4115 LED driver] ---> Blue LED+ (anode)
    Blue LED- (cathode) ---> MOSFET drain (Q2)
    MOSFET source (Q2) ---> GND
    ESP32 GPIO 26 ---> 220R ---> MOSFET gate (Q2)

    (Same topology as UV-A string above, GPIO 26 to Q2 gate)

    === UV-C LED (275nm) with Reed Switch Interlock ===

    NOTE: Most 275nm UV-C LEDs have Vf of 5.5-6.5V, which exceeds the
    5V rail. If your UV-C LED Vf > 5V, replace the current-limiting
    resistor with a 5V-to-9V boost converter module (MT3608 or similar).
    The base Void production design uses a boost stage for this reason
    (see FIRMWARE-DOCS.md Section 2.6). For prototype testing with a
    low-Vf UV-C LED (Vf < 4.5V), the resistor circuit below works.

    5V rail ---> UV-C LED+ (with current-limiting resistor or boost converter)
    UV-C LED- ---> Reed switch terminal A
    Reed switch terminal B ---> MOSFET drain (Q3)
    MOSFET source (Q3) ---> GND
    ESP32 GPIO 27 ---> 220R ---> MOSFET gate (Q3)

                  +5V
                   |
         [Resistor or Boost]
                   |
              UV-C LED (275nm)
                   |
             [Reed Switch]     <-- HARDWARE INTERLOCK
                   |               (open = dome removed = UV-C OFF)
             Drain |
        Q3 [IRLZ44N] MOSFET
             Source|
                   |
                  GND
        Gate <--- 220R <--- GPIO 27

    === 30mm 5V Fan (PWM speed control) ===

    5V rail ---> Fan+ (red wire)
    Fan- (black wire) ---> MOSFET drain (Q4)
    MOSFET source (Q4) ---> GND
    ESP32 GPIO 14 ---> 220R ---> MOSFET gate (Q4)

                  +5V
                   |
              Fan (30mm)
                   |
             Drain |
        Q4 [IRLZ44N] MOSFET
             Source|
                   |
                  GND
        Gate <--- 220R <--- GPIO 14

    === Piezo Humidifier Disc ===

    5V rail ---> Humidifier+ (red wire)
    Humidifier- (black wire) ---> MOSFET drain (Q5)
    MOSFET source (Q5) ---> GND
    ESP32 GPIO 13 ---> 220R ---> MOSFET gate (Q5)

    (Same topology as fan above, GPIO 13 to Q5 gate)

    === Reed Switch (Dome Presence) ===

    ESP32 GPIO 16 ---> Reed switch terminal A
    Reed switch terminal B ---> GND

    (Uses ESP32 internal pull-up; LOW when dome magnet closes switch)

    === 12mm Tactile Button ===

    ESP32 GPIO 17 ---> Button terminal A
    Button terminal B ---> GND

    (Uses ESP32 internal pull-up; LOW when pressed)

    === Red Indicator LED (UV-C Warning) ===

    ESP32 GPIO 2 ---> 220 ohm resistor ---> Red LED anode
    Red LED cathode ---> GND
```

---

## Power Notes

- **ESP32 powered via USB:** The ESP32 DevKit V1 is powered through its own micro-USB port, separate from the component 5V rail. The DevKit's onboard regulator provides 3.3V to the GPIO pins.

- **Component 5V rail:** All external components (LEDs, fan, humidifier, UV-C) are powered from a separate 5V USB-C rail via the CH224K PD sink IC (see FIRMWARE-DOCS.md Section 2.1). This isolates the ESP32 from high-current loads.

- **Power budget (from FIRMWARE-DOCS.md Section 4.5):**
  - Typical draw (normal growing): ~5.5W
  - Peak draw (all systems active): ~10W
  - Requires USB-C PD at 5V/3A (15W) for headroom

- **Ground bus:** All GND connections (ESP32 GND, 5V rail GND, all MOSFET sources, sensor GND) must share a common ground. Connect the ESP32 GND pin to the 5V rail GND.

- **MOSFET selection:** Use logic-level N-channel MOSFETs (IRLZ44N or equivalent) that fully turn on at 3.3V gate voltage. The ESP32 GPIO outputs are 3.3V -- standard (non-logic-level) MOSFETs will not fully saturate and may overheat.

---

## Component BOM

| Component | Qty | Specification | Notes |
|---|-----|---|---|
| ESP32 DevKit V1 | 1 | 38-pin, dual-core, Wi-Fi + BLE | Prototype controller |
| BME280 breakout | 1 | I2C, 3.3V, with pull-ups | Temperature / humidity / pressure sensor |
| 30mm axial fan | 1 | 5V DC | PWM speed control via MOSFET |
| Piezo humidifier disc | 1 | 20mm, 113 kHz | Ultrasonic mist generation |
| UV-A LEDs | 6 | 395nm, 20mA, 5050 SMD | Series string for grow lighting |
| Blue LEDs | 6 | 450nm, 20mA, 5050 SMD | Series string for fruiting light |
| UV-C LED | 1 | 275nm, 3535 SMD | Germicidal sterilization, with current-limiting resistor |
| Reed switch | 1 | Normally-open, glass body | Dome presence interlock |
| Neodymium magnet | 1 | 6x2mm disc | Embedded in dome seating lip |
| 12mm tactile button | 1 | Waterproof silicone cap | Mode cycling / UV-C trigger |
| Red 3mm LED | 1 | Standard through-hole | UV-C active indicator |
| N-channel MOSFETs | 5 | IRLZ44N or similar logic-level | LED / fan / humidifier switching |
| 220 ohm resistors | 6 | 1/4W | MOSFET gate resistors (Q1-Q5) + indicator LED current limiting |
| PT4115 LED driver | 1 | Constant-current, 20mA per string | Drives UV-A + Blue LED strings |

---

## UV-C Safety Warning

```
===========================================================================
  SAFETY: UV-C RADIATION HAZARD

  The UV-C LED (275nm) emits germicidal ultraviolet radiation that is
  harmful to eyes and skin. The dose inside the dome (90-180 mJ/cm2)
  is 15-30x the ACGIH 8-hour exposure limit for humans.

  - NEVER look directly at the UV-C LED when powered
  - ALWAYS ensure the dome is fully seated during sterilization
  - The hardware interlock prevents UV-C from activating without the
    dome, but you MUST verify it works before first use (see below)
  - The red indicator LED on the base lights during UV-C -- if it is
    on, do NOT remove the dome
  - If the interlock fails, IMMEDIATELY disconnect USB power
===========================================================================
```

**How the interlock works:**

The reed switch is wired **in series** with the UV-C LED power path. This is a physical circuit break, not a software check. The UV-C power path is:

```
5V rail --> [UV-C LED] --> [Reed switch] --> [MOSFET drain] --> GND
```

If the reed switch is open (dome removed), the circuit is broken and no current can flow to the UV-C LED. This works even if the ESP32 firmware crashes, hangs, or sets GPIO 27 HIGH permanently.

**Interlock test procedure (mandatory before first use):**

1. Seat the dome on the base and connect power
2. Trigger a UV-C sterilization cycle -- the red LED (GPIO 2) should light
3. While the red LED is on, carefully lift the dome off the base
4. The red LED should immediately turn off (UV-C power cut by reed switch)
5. Replace the dome -- UV-C should NOT restart (requires new trigger)

**If the interlock fails** (red LED stays on with dome removed): disconnect power immediately. Check reed switch wiring, magnet placement, and MOSFET connections.

---

*Part of the Void Blueprints firmware package.*
*See FIRMWARE-DOCS.md for complete electronics documentation.*

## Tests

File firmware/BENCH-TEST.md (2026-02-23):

# The Void -- Bench Test Procedure

> Comprehensive bench testing procedures for validating all Void Core firmware
> subsystems with physical hardware. Run all 9 tests after assembly and before
> first use.
>
> **References:**
> - [WIRING.md](WIRING.md) -- Pin assignments and circuit wiring
> - [UV-C-SAFETY-TEST.md](UV-C-SAFETY-TEST.md) -- Detailed UV-C safety tests

---

## Prerequisites

Before running any tests, verify the following:

- [ ] ESP32 DevKit V1 wired per [WIRING.md](WIRING.md)
- [ ] Components connected: BME280, at least 1 LED (UV-A or Blue), fan, button, reed switch + magnet, indicator LED
- [ ] Humidifier optional (can test control logic via Serial output)
- [ ] USB cable connected to ESP32
- [ ] Serial monitor at 115200 baud
- [ ] PlatformIO installed, firmware compiled and uploaded

## Upload Procedure

```
cd firmware
pio run --target upload
pio device monitor
```

Wait for the startup banner to appear before proceeding.

---

## Test 1 -- Boot & Initialization

Verifies that all firmware modules initialize correctly at power-on.

**Steps:**

1. Power on ESP32 (connect USB cable or press reset button)
2. Observe Serial monitor output

**Expected Results:**

- ASCII art "THE VOID" startup banner appears
- Firmware version displayed (e.g., `Void Core Firmware v0.1.0`)
- Each module reports initialization status:
  - `[Init] BME280 sensor... OK`
  - `[Init] LED controller... OK (mode X)`
  - `[Init] Button handler... OK`
  - `[Init] UV-C controller... OK`
  - `[Init] Climate controller... OK`
  - `[Init] Web server... OK (AP: VoidCore, IP: 192.168.4.1)`
- Final message: `Setup complete. All systems initialized.`

**Pass Criteria:**

All modules report initialized. If BME280 shows FAILED, check I2C wiring (SDA=GPIO 21, SCL=GPIO 22) but note that other modules should still function.

---

## Test 2 -- Sensor Readings

Verifies that the BME280 sensor returns valid environmental data.

**Steps:**

1. Wait 30 seconds after boot for the first sensor poll
2. Observe Serial output for BME280 readings
3. Breathe on the sensor to change humidity

**Expected Results:**

- Serial shows: `BME280: XX.X°C, XX.X% RH, XXXX.X hPa`
- Temperature is reasonable for room environment (18-30°C)
- Humidity increases noticeably when breathing on sensor
- Readings repeat every 30 seconds

**Pass Criteria:**

Readings change in response to environment. Values are within plausible ranges (temperature 10-50°C, humidity 10-100%, pressure 900-1100 hPa).

---

## Test 3 -- Button & LED Modes

Verifies button debounce, mode cycling, and LED pin state changes.

**Steps:**

1. Short press button (quick tap, < 1 second)
2. Observe Serial output and LED state change
3. Short press 3 more times to cycle through all modes
4. Verify each mode:
   - Mode 1 (Void Glow): UV-A ON, Blue ON
   - Mode 2 (UV Only): UV-A ON, Blue OFF
   - Mode 3 (Blue Only): UV-A OFF, Blue ON
   - Mode 4 (Off): UV-A OFF, Blue OFF
5. Press once more to cycle back to Mode 1 (Void Glow)

**Expected Results:**

- Serial shows `[Main] Mode cycled to: X` on each press
- LED pins change state to match the active mode
- No false triggers from button bounce
- Mode wraps from 4 back to 1

**Pass Criteria:**

All 4 modes cycle correctly. LEDs match expected on/off states for each mode. No double-triggers or missed presses.

---

## Test 4 -- UV-C Safety (CRITICAL)

Verifies all UV-C safety mechanisms. **This test is mandatory before first use.**

**Run all 4 tests from [UV-C-SAFETY-TEST.md](UV-C-SAFETY-TEST.md):**

1. Reed Switch Interlock Verification -- UV-C cannot activate without dome
2. Dome Removal Emergency Stop -- removing dome stops active UV-C immediately
3. Auto-Shutoff Timer -- UV-C stops after timeout (test with 10-second override)
4. No Restart After Dome Re-Seat -- UV-C does not auto-restart when dome is replaced

```
===========================================================================
  SAFETY: UV-C RADIATION HAZARD

  - NEVER look directly at the UV-C LED when powered
  - ALWAYS ensure the dome is fully seated during sterilization
  - If the interlock fails, IMMEDIATELY disconnect USB power
===========================================================================
```

**Pass Criteria:**

All 4 UV-C safety tests pass. See UV-C-SAFETY-TEST.md for detailed steps, expected results, and fail conditions.

---

## Test 5 -- Fan Control

Verifies that the fan responds to the climate controller based on humidity readings.

**Steps:**

1. Observe fan after boot -- it should spin at base speed (minimum duty for air circulation)
2. Breathe on BME280 sensor to spike humidity above setpoint (88% default)
3. Wait for the next sensor poll (30 seconds) and observe fan response
4. Allow humidity to drop back below setpoint and observe fan returning to base speed

**Expected Results:**

- Fan runs at base speed after boot (continuous FAE)
- When humidity exceeds setpoint + deadband (90%): fan speed increases for venting
- When humidity returns within deadband: fan returns to base speed
- Serial logs show climate controller status changes

**Pass Criteria:**

Fan responds to climate controller. Speed increases when humidity is above setpoint, returns to base when humidity normalizes.

---

## Test 6 -- Humidifier Control

Verifies humidifier activation in response to low humidity.

**Steps (with humidifier connected):**

1. Ensure ambient humidity is below setpoint (88% default)
2. Observe GPIO 13 -- humidifier should activate with duty cycling
3. Watch for misting behavior (on/off cycling over 10-second period)

**Steps (without humidifier -- Serial/multimeter only):**

1. Ensure ambient humidity is below setpoint
2. Monitor Serial output for climate controller log messages
3. Optionally: use multimeter on GPIO 13 to verify voltage toggling

**Expected Results:**

- Humidifier activates when humidity is below setpoint - deadband (86%)
- Duty cycling visible: GPIO 13 toggles high/low within each 10-second period
- Duty cycle is proportional to humidity deficit (larger deficit = longer on-time)
- Humidifier deactivates when humidity reaches setpoint

**Pass Criteria:**

Humidifier activates proportionally to humidity deficit. If not connected, verify GPIO 13 toggles via Serial log or multimeter reading.

---

## Test 7 -- Web Dashboard

Verifies WiFi AP, REST API, and dashboard functionality.

**Steps:**

1. On phone or laptop, connect to WiFi:
   - SSID: `VoidCore`
   - Password: `voidgrows`
2. Open browser to `http://192.168.4.1`
3. Verify dashboard loads with sensor readings
4. Test mode buttons -- LED should change on the device
5. Test climate settings -- change humidity setpoint, verify controller adjusts
6. Test sterilize button:
   - With dome seated: should start UV-C cycle (red indicator on)
   - Without dome: should show error/refusal

**Expected Results:**

- WiFi connection succeeds with SSID "VoidCore" and password "voidgrows"
- Dashboard loads at 192.168.4.1 with a responsive layout
- Sensor readings update approximately every 2 seconds
- Mode buttons change LED state and dashboard reflects the change
- Climate settings persist and controller adjusts behavior
- Sterilize button respects dome interlock

**Pass Criteria:**

All dashboard features functional. Sensor data displays and updates, controls work bidirectionally (dashboard changes hardware state, hardware changes reflect on dashboard).

---

## Test 8 -- 12-Hour Light Cycle (Abbreviated)

Verifies the automatic day/night light cycle timer.

**Steps:**

1. In `firmware/src/config.h`, temporarily change:
   ```cpp
   constexpr unsigned long LIGHT_CYCLE_MS = 30000UL;  // 30 seconds for testing
   ```
2. Rebuild and upload firmware: `pio run --target upload`
3. Set LED mode to Void Glow (mode 1) so lights are visible
4. Observe lights toggle on/off every 30 seconds
5. After verifying at least 2 full cycles (on -> off -> on), restore original value:
   ```cpp
   constexpr unsigned long LIGHT_CYCLE_MS = 43200000UL;  // 12 hours
   ```
6. Rebuild and upload firmware

**Expected Results:**

- Lights turn on for 30 seconds, then off for 30 seconds
- Cycle repeats automatically without user interaction
- Serial output reflects cycle state changes
- LED mode is preserved across cycle transitions (e.g., UV Only stays UV Only)

**Pass Criteria:**

Lights auto-toggle on the configured schedule. Restore 12-hour value after test.

---

## Test 9 -- Power Cycle Persistence

Verifies that the LED mode persists across reboots via ESP32 Preferences (NVS).

**Steps:**

1. Set a specific light mode (e.g., short press to Blue Only / mode 3)
2. Verify Serial shows `[Main] Mode cycled to: 3`
3. Disconnect USB power (unplug cable)
4. Wait 3 seconds
5. Reconnect USB power
6. Observe boot sequence and restored mode

**Expected Results:**

- After reboot, Serial shows `[Init] LED controller... OK (mode 3)`
- Blue LED is on, UV-A LED is off (matching Blue Only mode)
- No need to re-set mode after power loss

**Pass Criteria:**

Mode persists across power cycles. ESP32 boots into the previously selected mode.

---

## Test Summary

| # | Test | Status | Notes |
|---|---|---|---|
| 1 | Boot & Initialization | [ ] | |
| 2 | Sensor Readings | [ ] | |
| 3 | Button & LED Modes | [ ] | |
| 4 | UV-C Safety (CRITICAL) | [ ] | |
| 5 | Fan Control | [ ] | |
| 6 | Humidifier Control | [ ] | |
| 7 | Web Dashboard | [ ] | |
| 8 | 12-Hour Light Cycle | [ ] | |
| 9 | Power Cycle Persistence | [ ] | |

**Date tested:** _______________

**Tester:** _______________

**Firmware version:** _______________

**All tests passed:** [ ] Yes / [ ] No

---

*Part of the Void Blueprints firmware package.*
*See [WIRING.md](WIRING.md) for circuit wiring reference.*
*See [UV-C-SAFETY-TEST.md](UV-C-SAFETY-TEST.md) for detailed UV-C safety validation.*

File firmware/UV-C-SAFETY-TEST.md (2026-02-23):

# UV-C Sterilization Safety Test Procedure

```
===========================================================================
  SAFETY: UV-C RADIATION HAZARD

  The UV-C LED (275nm) emits germicidal ultraviolet radiation that is
  harmful to eyes and skin. The dose inside the dome (90-180 mJ/cm2)
  is 15-30x the ACGIH 8-hour exposure limit for humans.

  - NEVER look directly at the UV-C LED when powered
  - ALWAYS ensure the dome is fully seated during sterilization
  - The hardware interlock prevents UV-C from activating without the
    dome, but you MUST verify it works before first use (see below)
  - The red indicator LED on the base lights during UV-C -- if it is
    on, do NOT remove the dome
  - If the interlock fails, IMMEDIATELY disconnect USB power
===========================================================================
```

## Pre-Test Requirements

Before running any tests, verify the following:

- [ ] Reed switch wired **in series** with UV-C LED power line (verify wiring before powering on)
- [ ] Dome with embedded neodymium magnet available
- [ ] USB power source connected to ESP32
- [ ] Serial monitor open at 115200 baud
- [ ] Fire extinguisher accessible (electronics bench safety)

---

## Test 1 -- Reed Switch Interlock Verification

Verifies that UV-C cannot activate when the dome is not present.

**Steps:**

1. Remove dome from base (ensure magnet is not near reed switch)
2. Press and hold the button for 3+ seconds, then release

**Expected Results:**

- Serial log shows `[UVC] UV-C REFUSED: dome not detected`
- Serial log shows `[Main] UV-C refused -- grow lights restored`
- Red indicator LED (GPIO 2) stays OFF
- UV-C LED does NOT illuminate

**Fail Condition:**

Red indicator LED turns on, or UV-C LED illuminates without dome present. **DISCONNECT POWER IMMEDIATELY.** Check reed switch wiring -- it must be in series with UV-C power, not just a software input.

---

## Test 2 -- Dome Removal Emergency Stop

Verifies that removing the dome during an active UV-C cycle immediately stops sterilization.

**Steps:**

1. Seat dome on base (magnet closes reed switch)
2. Press and hold the button for 3+ seconds, then release
3. Confirm red indicator LED turns on and Serial shows `[UVC] UV-C STARTED: 15-minute sterilization cycle`
4. While red LED is on, carefully lift the dome off the base

**Expected Results:**

- Red indicator LED immediately turns off
- Serial log shows `[UVC] UV-C EMERGENCY STOP: dome removed during sterilization`
- Serial log shows `[Main] UV-C cycle complete -- grow lights restored`

**Fail Condition:**

Red indicator LED stays on after dome removal. **DISCONNECT POWER IMMEDIATELY.** The hardware interlock (reed switch in series) should have cut power at the hardware level regardless -- if the LED stays on, the reed switch is not wired in series. Fix wiring before proceeding.

---

## Test 3 -- Auto-Shutoff Timer

Verifies that UV-C automatically stops after the timeout period.

**Steps:**

1. In `firmware/src/config.h`, temporarily change `UVC_TIMEOUT_MS` to `10000UL` (10 seconds)
2. Rebuild and flash firmware
3. Seat dome on base
4. Press and hold the button for 3+ seconds, then release
5. Wait 10 seconds without touching anything

**Expected Results:**

- Red indicator LED turns off automatically after 10 seconds
- Serial log shows `[UVC] UV-C AUTO-SHUTOFF: 15 minutes elapsed`
- Serial log shows `[Main] UV-C cycle complete -- grow lights restored`

**After Test:**

Restore `UVC_TIMEOUT_MS` to `900000UL` (15 minutes) in `config.h` and reflash.

---

## Test 4 -- No Restart After Dome Re-Seat

Verifies that UV-C does not automatically restart when the dome is replaced after an emergency stop.

**Steps:**

1. Seat dome on base
2. Press and hold the button for 3+ seconds to start UV-C cycle
3. Remove dome (emergency stop triggers -- red LED turns off)
4. Replace dome on base
5. Wait 5 seconds

**Expected Results:**

- UV-C does NOT restart automatically after dome is replaced
- Red indicator LED stays OFF
- A new 3-second button hold is required to start a new UV-C cycle

**Fail Condition:**

UV-C restarts automatically when dome is replaced. This indicates the `startSterilization()` function is being called on dome re-seat rather than only on button long press. Fix the main loop logic -- UV-C should only start from the `LONG_PRESS` handler.

---

## Pass Criteria

All 4 tests must pass before the UV-C sterilization feature is considered safe for use.

| Test | Result | Date | Tester |
|---|---|---|---|
| 1. Reed Switch Interlock | | | |
| 2. Dome Removal Emergency Stop | | | |
| 3. Auto-Shutoff Timer | | | |
| 4. No Restart After Dome Re-Seat | | | |

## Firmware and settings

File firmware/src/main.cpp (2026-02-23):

// =============================================================================
// The Void -- Main Firmware Entry Point
// =============================================================================
//
// Complete firmware integration for the Void Core ESP32 prototype.
// All 8 modules initialized in dependency order, non-blocking loop with
// millis()-based task scheduling.
//
// Module initialization order:
//   1. SensorReader      -- BME280 I2C (no dependencies)
//   2. LedController     -- UV-A/Blue LED pins + Preferences restore
//   3. ButtonHandler     -- GPIO 17 INPUT_PULLUP
//   4. UvcController     -- UV-C trigger + reed switch + indicator
//   5. FanController     -- LEDC hardware PWM (initialized via ClimateController)
//   6. HumidifierController -- GPIO 13 output (initialized via ClimateController)
//   7. ClimateController -- refs: SensorReader, FanController, HumidifierController
//   8. VoidWebServer     -- refs: SensorReader, LedController, UvcController, ClimateController
//
// UV-C / LED integration:
//   - Long press starts sterilization: grow lights disabled, UV-C activated
//   - Long press during active UV-C: stops sterilization, grow lights restored
//   - UV-C auto-shutoff or emergency stop: grow lights restored automatically
//
// =============================================================================

#include <Arduino.h>
#include "config.h"
#include "sensor_reader.h"
#include "led_controller.h"
#include "button_handler.h"
#include "uvc_controller.h"
#include "fan_controller.h"
#include "humidifier_controller.h"
#include "climate_controller.h"
#include "web_server.h"

// -----------------------------------------------------------------------------
// Global Instances (ordered by initialization dependencies)
// -----------------------------------------------------------------------------

SensorReader         sensorReader;
LedController        ledController;
ButtonHandler        buttonHandler;
UvcController        uvcController;
FanController        fanController;
HumidifierController humidifierController;
ClimateController    climateController(sensorReader, fanController, humidifierController);
VoidWebServer        webServer(sensorReader, ledController, uvcController, climateController);

// -----------------------------------------------------------------------------
// State
// -----------------------------------------------------------------------------

static unsigned long lastSensorRead = 0;
static bool wasUvcActive = false;  // Tracks UV-C state to detect cycle completion

// -----------------------------------------------------------------------------
// Helper: Cycle light mode 1 -> 2 -> 3 -> 4 -> 1
// -----------------------------------------------------------------------------

static LightMode nextMode(LightMode current) {
    uint8_t m = static_cast<uint8_t>(current) + 1;
    if (m > static_cast<uint8_t>(LightMode::OFF)) {
        m = static_cast<uint8_t>(LightMode::VOID_GLOW);
    }
    return static_cast<LightMode>(m);
}

// -----------------------------------------------------------------------------
// Setup
// -----------------------------------------------------------------------------

void setup() {
    Serial.begin(115200);

    // --- Startup banner ---
    Serial.println();
    Serial.println("========================================");
    Serial.println("  _____ _  _ ___  __   ___  ___ ___    ");
    Serial.println(" |_   _| || | __| \\ \\ / / \\|_ _|   \\  ");
    Serial.println("   | | | __ | _|   \\ V / O || || |) |  ");
    Serial.println("   |_| |_||_|___|   \\_/ \\___/___|___/  ");
    Serial.println("========================================");
    Serial.print("  Void Core Firmware v");
    Serial.println(FIRMWARE_VERSION);
    Serial.println("  ESP32 Prototype");
    Serial.println("========================================");
    Serial.println();

    // --- Module initialization (dependency order) ---

    // 1. BME280 sensor — warn but don't halt if not found
    Serial.print("[Init] BME280 sensor... ");
    if (sensorReader.begin()) {
        Serial.println("OK");
    } else {
        Serial.println("FAILED (check wiring — climate runs in manual mode)");
    }

    // 2. LED controller (restores last mode from Preferences)
    Serial.print("[Init] LED controller... ");
    ledController.begin();
    Serial.print("OK (mode ");
    Serial.print(static_cast<int>(ledController.getMode()));
    Serial.println(")");

    // 3. Button handler (GPIO 17, INPUT_PULLUP)
    Serial.print("[Init] Button handler... ");
    buttonHandler.begin();
    Serial.println("OK");

    // 4. UV-C sterilization controller
    Serial.print("[Init] UV-C controller... ");
    uvcController.begin();
    // uvcController.begin() prints its own status

    // 5-7. Climate controller (also initializes fan and humidifier)
    Serial.print("[Init] Climate controller... ");
    climateController.begin();
    Serial.println("OK");

    // 8. Web dashboard (WiFi AP + REST API + SPIFFS)
    Serial.print("[Init] Web server... ");
    webServer.begin();
    Serial.print("OK (AP: ");
    Serial.print(AP_SSID);
    Serial.print(", IP: ");
    Serial.print(webServer.getIPAddress());
    Serial.println(")");

    Serial.println();
    Serial.println("========================================");
    Serial.println("  Setup complete. All systems initialized.");
    Serial.println("========================================");
    Serial.println();
}

// -----------------------------------------------------------------------------
// Main Loop (non-blocking, millis()-based scheduling)
// -----------------------------------------------------------------------------

void loop() {
    unsigned long now = millis();

    // -------------------------------------------------------------------------
    // 1. Button input (runs every iteration for responsive input)
    // -------------------------------------------------------------------------
    ButtonEvent event = buttonHandler.update();

    if (event == ButtonEvent::SHORT_PRESS) {
        // Cycle LED mode: 1 -> 2 -> 3 -> 4 -> 1
        LightMode next = nextMode(ledController.getMode());
        ledController.setMode(next);
        Serial.print("[Main] Mode cycled to: ");
        Serial.println(static_cast<int>(next));

    } else if (event == ButtonEvent::LONG_PRESS) {
        if (uvcController.isActive()) {
            // UV-C is running — stop sterilization and restore grow lights
            uvcController.stop();
            ledController.setLightsEnabled(true);
            Serial.println("[Main] UV-C manually stopped — grow lights restored");
        } else {
            // UV-C is not running — disable grow lights and start sterilization
            ledController.setLightsEnabled(false);

            if (!uvcController.startSterilization()) {
                // UV-C refused (dome not seated) — restore grow lights
                ledController.setLightsEnabled(true);
                Serial.println("[Main] UV-C refused — grow lights restored");
            }
        }
    }

    // -------------------------------------------------------------------------
    // 2. LED 12-hour cycle timer
    // -------------------------------------------------------------------------
    ledController.update();

    // -------------------------------------------------------------------------
    // 3. UV-C sterilization controller (auto-shutoff + reed switch monitoring)
    // -------------------------------------------------------------------------
    uvcController.update();

    // Detect UV-C cycle completion: restore grow lights when UV-C finishes
    // (handles auto-shutoff and emergency stop — not manual stop, which is
    // handled above in the LONG_PRESS handler)
    if (wasUvcActive && !uvcController.isActive()) {
        ledController.setLightsEnabled(true);
        Serial.println("[Main] UV-C cycle complete — grow lights restored");
    }
    wasUvcActive = uvcController.isActive();

    // -------------------------------------------------------------------------
    // 4. Sensor polling (non-blocking, SENSOR_POLL_MS interval)
    // -------------------------------------------------------------------------
    if (now - lastSensorRead >= SENSOR_POLL_MS || lastSensorRead == 0) {
        lastSensorRead = now;

        if (sensorReader.read()) {
            const SensorData& d = sensorReader.getData();
            Serial.print("BME280: ");
            Serial.print(d.temperature, 1);
            Serial.print("\xC2\xB0""C, ");
            Serial.print(d.humidity, 1);
            Serial.print("% RH, ");
            Serial.print(d.pressure, 1);
            Serial.println(" hPa");

            // Climate control runs after each successful sensor read
            climateController.update();
        } else {
            Serial.println("BME280: read failed");
        }
    }

    // -------------------------------------------------------------------------
    // 5. Humidifier software PWM (must run every loop iteration)
    // -------------------------------------------------------------------------
    humidifierController.update();
}

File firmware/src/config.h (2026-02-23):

// =============================================================================
// The Void -- Firmware Configuration
// =============================================================================
//
// All pin assignments, timing constants, climate setpoints, and system
// defaults for the Void Core ESP32 prototype.
//
// Pin assignments must match firmware/WIRING.md.
// Timing and climate values sourced from FIRMWARE-DOCS.md.
//
// =============================================================================

#ifndef VOID_CONFIG_H
#define VOID_CONFIG_H

// -----------------------------------------------------------------------------
// Firmware Version
// -----------------------------------------------------------------------------

constexpr const char* FIRMWARE_VERSION = "0.1.0";

// -----------------------------------------------------------------------------
// Pin Assignments (ESP32 DevKit V1)
// See firmware/WIRING.md for wiring diagram and circuit details.
// -----------------------------------------------------------------------------

// I2C -- BME280 sensor
constexpr int PIN_SDA        = 21;  // GPIO 21: BME280 I2C data (bidirectional)
constexpr int PIN_SCL        = 22;  // GPIO 22: BME280 I2C clock (output)

// LED control -- active HIGH, drives N-channel MOSFET gate
constexpr int PIN_UVA        = 25;  // GPIO 25: UV-A LED string enable
constexpr int PIN_BLUE       = 26;  // GPIO 26: Blue LED string enable
constexpr int PIN_UVC        = 27;  // GPIO 27: UV-C trigger (reed switch in series)

// Actuators
constexpr int PIN_FAN_PWM    = 14;  // GPIO 14: Fan PWM (hardware PWM via LEDC)
constexpr int PIN_HUMIDIFIER = 13;  // GPIO 13: Humidifier enable (MOSFET gate)

// Inputs -- internal pull-up, active LOW
constexpr int PIN_REED       = 16;  // GPIO 16: Reed switch (LOW = dome seated)
constexpr int PIN_BUTTON     = 17;  // GPIO 17: Button (LOW = pressed)

// Indicator
constexpr int PIN_INDICATOR  = 2;   // GPIO 2: Red LED (active HIGH, built-in on most DevKits)

// -----------------------------------------------------------------------------
// Timing Constants
// From FIRMWARE-DOCS.md Section 3.3
// -----------------------------------------------------------------------------

constexpr unsigned long LIGHT_CYCLE_MS    = 43200000UL;  // 12 hours in ms
constexpr unsigned long UVC_TIMEOUT_MS    = 900000UL;    // 15 minutes in ms
constexpr unsigned long BUTTON_HOLD_MS    = 3000UL;      // 3-second hold threshold
constexpr unsigned long BUTTON_DEBOUNCE_MS = 50UL;       // Button debounce time

// -----------------------------------------------------------------------------
// Sensor Constants
// -----------------------------------------------------------------------------

constexpr unsigned long SENSOR_POLL_MS    = 30000UL;     // 30-second sensor polling interval

// -----------------------------------------------------------------------------
// Climate Constants
// From FIRMWARE-DOCS.md Section 4.3
// -----------------------------------------------------------------------------

constexpr float HUMIDITY_SETPOINT  = 88.0f;   // Target RH% (user-adjustable 80-95%)
constexpr float HUMIDITY_DEADBAND  = 2.0f;    // +/- RH% deadband around setpoint
constexpr int   CO2_WARNING        = 600;     // ppm -- fan speed starts increasing
constexpr int   CO2_ALARM          = 1000;    // ppm -- maximum fan speed, app notification

// -----------------------------------------------------------------------------
// Fan PWM Constants
// -----------------------------------------------------------------------------

constexpr int FAN_PWM_CHANNEL    = 0;      // LEDC channel for fan PWM
constexpr int FAN_PWM_FREQ       = 25000;  // 25 kHz PWM frequency
constexpr int FAN_PWM_RESOLUTION = 8;      // 8-bit resolution (0-255)
constexpr int FAN_MIN_DUTY       = 50;     // Minimum duty cycle (fan stall threshold)
constexpr int FAN_MAX_DUTY       = 255;    // Maximum duty cycle (full speed)

// -----------------------------------------------------------------------------
// WiFi Defaults
// -----------------------------------------------------------------------------

constexpr const char* AP_SSID     = "VoidCore";
constexpr const char* AP_PASSWORD = "voidgrows";

#endif // VOID_CONFIG_H

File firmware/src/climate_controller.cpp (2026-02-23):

// =============================================================================
// The Void -- Climate Controller Implementation
// =============================================================================

#include "climate_controller.h"
#include "config.h"
#include <Preferences.h>

// Preferences namespace for climate settings
static const char* CLIMATE_NS = "climate";

// =============================================================================
// Constructor
// =============================================================================

ClimateController::ClimateController(SensorReader& sensor, FanController& fan,
                                     HumidifierController& humidifier)
    : sensorReader(sensor)
    , fanController(fan)
    , humidifierController(humidifier)
{
}

// =============================================================================
// Initialization
// =============================================================================

void ClimateController::begin() {
    // Initialize actuators
    fanController.begin();
    humidifierController.begin();

    // Load saved settings from NVS
    loadSettings();

    // Start fan at base speed for continuous air circulation
    fanController.setSpeed(settings.fanBaseSpeed);

    Serial.println("[Climate] Initialized");
    Serial.print("[Climate] Setpoint: ");
    Serial.print(settings.humiditySetpoint, 1);
    Serial.print("% +/- ");
    Serial.print(settings.humidityDeadband, 1);
    Serial.print("%, Auto: ");
    Serial.println(settings.autoMode ? "ON" : "OFF");
}

// =============================================================================
// Main Control Loop
// =============================================================================

void ClimateController::update() {
    // Only control in auto mode
    if (!settings.autoMode) {
        return;
    }

    // Only act on valid sensor data
    const SensorData& data = sensorReader.getData();
    if (!data.valid) {
        return;
    }

    float humidity = data.humidity;
    float setpoint = settings.humiditySetpoint;
    float deadband = settings.humidityDeadband;
    unsigned long now = millis();

    // --- Humidity LOW: activate humidifier proportionally ---
    if (humidity < (setpoint - deadband)) {
        float deficit = setpoint - humidity;

        // Proportional duty: deficit/10 gives 0.0-1.0 range
        // 5% below setpoint -> 50% duty, 10%+ below -> 100% duty
        float duty = deficit / 10.0f;
        if (duty > 1.0f) duty = 1.0f;

        humidifierController.setDutyCycle(duty);
        humidifierController.setEnabled(true);

        // Keep fan at base speed -- don't blow away the mist
        fanController.setSpeed(settings.fanBaseSpeed);
        ventingActive = false;

        Serial.print("[Climate] ");
        Serial.print(humidity, 1);
        Serial.print("% RH (target ");
        Serial.print(setpoint, 0);
        Serial.print("+/-");
        Serial.print(deadband, 0);
        Serial.print(") | Fan: ");
        Serial.print((settings.fanBaseSpeed * 100) / 255);
        Serial.print("% | Humidifier: ");
        Serial.print(static_cast<int>(duty * 100));
        Serial.println("% duty");
    }
    // --- Humidity HIGH: vent with fan ---
    else if (humidity > (setpoint + deadband)) {
        // Disable humidifier
        humidifierController.setEnabled(false);

        // Start or continue venting at 80% fan speed
        if (!ventingActive) {
            ventingActive = true;
            ventStartTime = now;
            fanController.setSpeedPercent(80.0f);
        }

        // After 30 seconds, return to base speed
        if (ventingActive && (now - ventStartTime >= VENT_DURATION_MS)) {
            fanController.setSpeed(settings.fanBaseSpeed);
            ventingActive = false;
        }

        Serial.print("[Climate] ");
        Serial.print(humidity, 1);
        Serial.print("% RH (target ");
        Serial.print(setpoint, 0);
        Serial.print("+/-");
        Serial.print(deadband, 0);
        Serial.print(") | Fan: ");
        Serial.print(ventingActive ? "VENTING 80%" : "base");
        Serial.println(" | Humidifier: OFF");
    }
    // --- Within deadband: steady state ---
    else {
        humidifierController.setEnabled(false);
        fanController.setSpeed(settings.fanBaseSpeed);
        ventingActive = false;

        Serial.print("[Climate] ");
        Serial.print(humidity, 1);
        Serial.print("% RH (target ");
        Serial.print(setpoint, 0);
        Serial.print("+/-");
        Serial.print(deadband, 0);
        Serial.println(") | Fan: base | Humidifier: OFF | Steady state");
    }
}

// =============================================================================
// Settings Management
// =============================================================================

void ClimateController::setSettings(const ClimateSettings& s) {
    settings = s;
    saveSettings();

    // Apply immediately
    if (settings.autoMode) {
        fanController.setSpeed(settings.fanBaseSpeed);
    }

    Serial.print("[Climate] Settings updated: ");
    Serial.print(settings.humiditySetpoint, 1);
    Serial.print("% +/- ");
    Serial.print(settings.humidityDeadband, 1);
    Serial.println("%");
}

const ClimateSettings& ClimateController::getSettings() const {
    return settings;
}

bool ClimateController::isHumidifierActive() const {
    return humidifierController.isEnabled();
}

uint8_t ClimateController::getCurrentFanSpeed() const {
    return fanController.getSpeed();
}

String ClimateController::getStatus() const {
    const SensorData& data = sensorReader.getData();

    String status = "Climate: ";

    if (data.valid) {
        status += String(data.humidity, 1) + "% RH";
    } else {
        status += "no data";
    }

    status += " (target " + String(settings.humiditySetpoint, 0);
    status += "+/-" + String(settings.humidityDeadband, 0) + ")";
    status += " | Fan: " + String((fanController.getSpeed() * 100) / 255) + "%";
    status += " | Humidifier: ";
    status += humidifierController.isEnabled() ? "ON" : "OFF";
    status += " | Mode: ";
    status += settings.autoMode ? "AUTO" : "MANUAL";

    return status;
}

// =============================================================================
// Preferences Persistence
// =============================================================================

void ClimateController::saveSettings() {
    Preferences prefs;
    prefs.begin(CLIMATE_NS, false);
    prefs.putFloat("setpoint", settings.humiditySetpoint);
    prefs.putFloat("deadband", settings.humidityDeadband);
    prefs.putUChar("fanBase", settings.fanBaseSpeed);
    prefs.putBool("autoMode", settings.autoMode);
    prefs.end();
}
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

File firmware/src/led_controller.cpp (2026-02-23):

// =============================================================================
// The Void -- LED Controller Implementation
// =============================================================================

#include "led_controller.h"
#include "config.h"
#include <Preferences.h>

// Preferences namespace and key for persistent mode storage
static const char* PREFS_NAMESPACE = "void";
static const char* PREFS_MODE_KEY  = "lightMode";

// -----------------------------------------------------------------------------
// begin()
// -----------------------------------------------------------------------------

void LedController::begin() {
    // Configure LED pins as outputs, start LOW (off)
    pinMode(PIN_UVA, OUTPUT);
    pinMode(PIN_BLUE, OUTPUT);
    digitalWrite(PIN_UVA, LOW);
    digitalWrite(PIN_BLUE, LOW);

    // Restore last mode from Preferences (ESP32 flash-backed key-value store)
    Preferences prefs;
    prefs.begin(PREFS_NAMESPACE, true);  // read-only
    uint8_t stored = prefs.getUChar(PREFS_MODE_KEY, 0);
    prefs.end();

    if (stored >= static_cast<uint8_t>(LightMode::VOID_GLOW) &&
        stored <= static_cast<uint8_t>(LightMode::OFF)) {
        currentMode = static_cast<LightMode>(stored);
    } else {
        currentMode = LightMode::VOID_GLOW;
    }

    // Initialize cycle state
    lightsEnabled  = true;
    lightCycleOn   = true;
    cycleStartTime = millis();

    Serial.print("[LED] Mode restored: ");
    Serial.println(static_cast<int>(currentMode));

    applyMode();
}

// -----------------------------------------------------------------------------
// setMode()
// -----------------------------------------------------------------------------

void LedController::setMode(LightMode mode) {
    currentMode = mode;

    // Persist to Preferences
    Preferences prefs;
    prefs.begin(PREFS_NAMESPACE, false);  // read-write
    prefs.putUChar(PREFS_MODE_KEY, static_cast<uint8_t>(mode));
    prefs.end();

    Serial.print("[LED] Mode set: ");
    Serial.println(static_cast<int>(currentMode));

    applyMode();
}

// -----------------------------------------------------------------------------
// getMode()
// -----------------------------------------------------------------------------

LightMode LedController::getMode() const {
    return currentMode;
}

// -----------------------------------------------------------------------------
// update()
// -----------------------------------------------------------------------------

void LedController::update() {
    unsigned long now = millis();

    if (now - cycleStartTime >= LIGHT_CYCLE_MS) {
        lightCycleOn   = !lightCycleOn;
        cycleStartTime = now;

        Serial.print("[LED] 12h cycle: ");
        Serial.println(lightCycleOn ? "DAY (lights on)" : "NIGHT (lights off)");

        applyMode();
    }
}

// -----------------------------------------------------------------------------
// setLightsEnabled()
// -----------------------------------------------------------------------------

void LedController::setLightsEnabled(bool enabled) {
    lightsEnabled = enabled;

    Serial.print("[LED] Lights enabled: ");
    Serial.println(enabled ? "true" : "false");

    applyMode();
}

// -----------------------------------------------------------------------------
// isLightCycleOn()
// -----------------------------------------------------------------------------

bool LedController::isLightCycleOn() const {
    return lightCycleOn;
}

// -----------------------------------------------------------------------------
// applyMode() — private
// -----------------------------------------------------------------------------

void LedController::applyMode() {
    // If lights are disabled (UV-C sterilization) or in night phase,
    // force both pins LOW regardless of mode.
    if (!lightsEnabled || !lightCycleOn) {
        digitalWrite(PIN_UVA, LOW);
        digitalWrite(PIN_BLUE, LOW);
        return;
    }

    switch (currentMode) {
        case LightMode::VOID_GLOW:
            digitalWrite(PIN_UVA, HIGH);
            digitalWrite(PIN_BLUE, HIGH);
            break;
        case LightMode::UV_ONLY:
            digitalWrite(PIN_UVA, HIGH);
            digitalWrite(PIN_BLUE, LOW);
            break;
        case LightMode::BLUE_ONLY:
            digitalWrite(PIN_UVA, LOW);
            digitalWrite(PIN_BLUE, HIGH);
            break;
        case LightMode::OFF:
            digitalWrite(PIN_UVA, LOW);
            digitalWrite(PIN_BLUE, LOW);
            break;
    }
}

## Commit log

2026-02-23 Initial release: open-source hardware, firmware, and build docs
    CAD (OpenSCAD source + STL exports), ESP32 firmware, and complete build
    documentation for The Void mushroom cultivation dome.
    Hardware: CERN-OHL-P-2.0 | Firmware: MIT | Docs: CC BY 4.0
    [assembly.scad, base.scad, dome.scad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]
2026-02-23 Add GitHub Action to auto-upload STLs on release
    Automatically attaches all STL files from cad/export/stl/ as release
    assets when a new version tag (v*) is pushed.
2026-02-23 feat: golden ratio cloche redesign (v0.1.0)
    Replace spherical dome with golden ratio cloche proportions:
    - Dome: 203mm dia × 266mm H (straight walls + arch cap)
    - Base: 211mm dia × 39mm H (R/φ² height)
    - Total: 304.5mm (12")
    All proportions derived from φ = 1.618.
    [assembly.scad, base.scad, cloche_preview.scad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]
